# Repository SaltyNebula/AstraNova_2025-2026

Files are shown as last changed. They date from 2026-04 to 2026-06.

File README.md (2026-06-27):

# AstraNova: UKSEDS National Rocketry Championship 2025-26

**UKC AstraNova** is a student rocketry team from the **University of Kent**, competing in the **UKSEDS National Rocketry Championship (NRC) 2025-26**. This repository is the team's full project record, organised by subsystem; propulsion, structures, recovery, the customer payload, the avionics and rideshare payload, the systems engineering and design reviews, and the supporting documentation. The mission: design, build, and fly a rocket that reaches **670 m**, carries a customer payload alongside the team's own rideshare payload, records its flight data on-board, and recovers safely within **1 km** of the launch site.

> **Flight outcome:** the rocket flew a clean, stable, vertical boost, which validated the aerodynamic and stability design. At apogee it pitched over rather than nosing straight down, so the recovery flight computer's near-freefall deployment condition never triggered and the vehicle came in ballistic. The airframe was lost; the avionics board survived intact. The team took home a UKSEDS **"RUD of the Day"** plaque. The recovery and avionics failures are diagnosed honestly in the [post-mortem](#flight-outcome-and-post-mortem).

AstraNova rocket

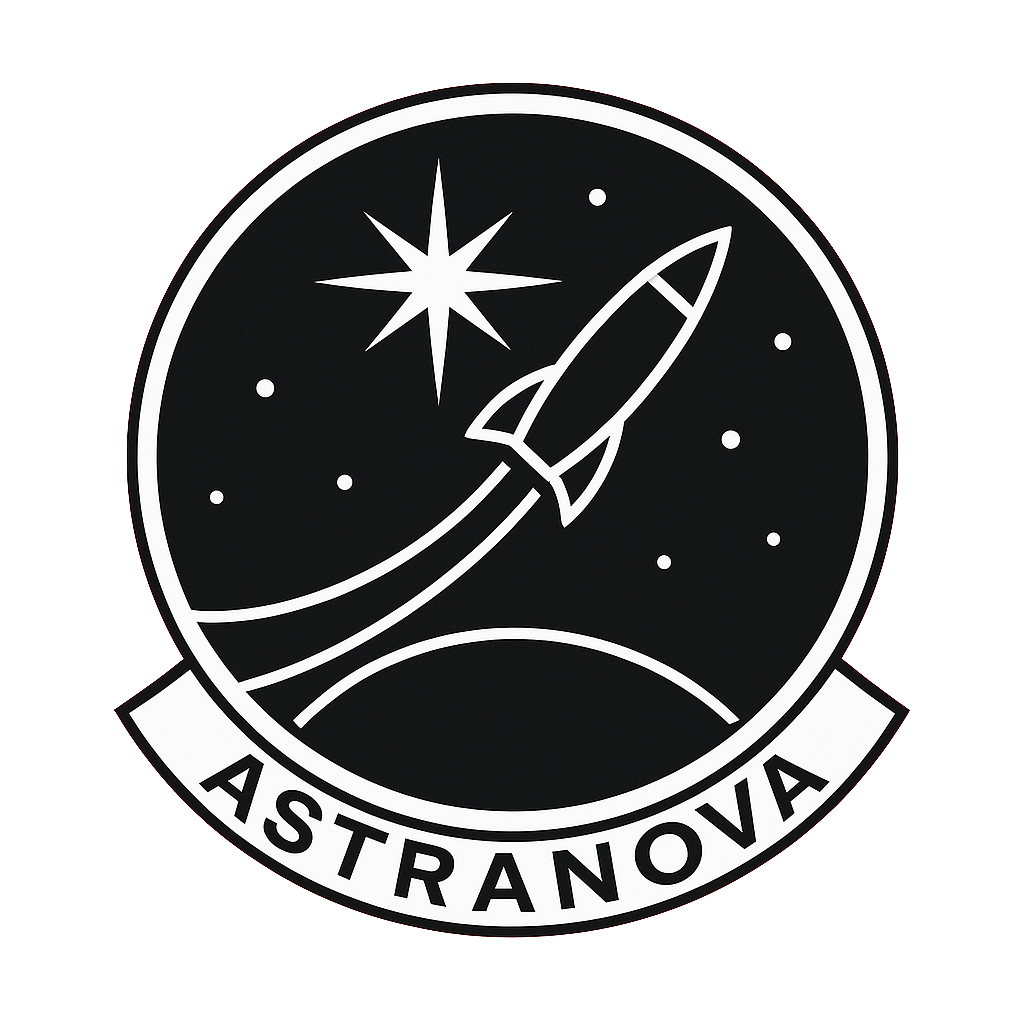
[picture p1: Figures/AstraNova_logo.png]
Team Logo


## Summary

The vehicle is a 68.9 cm, 769 g cardboard-airframe rocket flying on a **Cesaroni Pro29 108G68-13A** motor (2-grain 29 mm, 107.8 Ns total impulse, ~1.6 s near-constant burn), targeting **670 m (about 2200 ft)**. It carries two payloads: a competition **customer payload (CPD)** powered from the airframe, and the team's own **rideshare payload (the RPD)**. The RPD is a custom flight data logger that records the flight and reports peak altitude on board. Stability sits between *1.75 to 2.5 calibre** throughout ascent, and the final design clears the rail at **19.7 m/s**. Recovery is a nose-cone separation event driven by a flash-paper ejection charge and a **Mercury V1** flight computer on an isolated battery, deploying a 24" Spherachute. The project is documented end to end through the Critical Design Review, Manufacturing Review, and Flight Readiness Review, with a full requirement compliance matrix and mass, power, and financial budgets. The rocket flew, the ascent was stable and straight, and two things then went wrong; both are written up below because the lessons are the real output.

## Key points

- **Mission.** Reach 670 m, carry both payloads, retrieve flight data, and recover within 1 km of the pad, in full compliance with UKSEDS NRC safety rules.
- **Propulsion.** Cesaroni Pro29 108G68-13A; a 2-grain 29 mm motor chosen for its near-constant thrust, giving a steady burn and enough early thrust to clear the rail at speed.
- **Structures.** Cardboard body tube (about 50 mm internal diameter), four lightweight plywood trapezoidal fins, and an ABS-GF (glass-filled ABS) Ogive nose cone with a tight-fitting shoulder; total length 68.9 cm, mass 769 g, validated to hold a 2 kg suspended load without significant deflection.
- **Stability and ascent.** Stability margin held at 2.44 calibres; rail exit at 19.7 m/s; the flight confirmed a stable, vertical boost.
- **Recovery.** Mercury V1 altimeter and flight computer on an independent, isolated battery; flash-paper ejection charge fired by an igniter; nose-cone separation; 24" Spherachute with swivel; Kevlar shock cords over 2 m.
- **Customer payload (CPD).** Powered over a regulated 5 V bus through a keyed XT30 connector from a 4 A buck converter; unpressurised bay for barometric operation; mounted on a removable 3D-printed avionics sled with a bayonet-style twist lock.
- **Rideshare avionics (the RPD).** A from-scratch 2-layer PCB (102 g installed); Raspberry Pi Pico 2 (RP2350), Waveshare 10-DOF IMU (ICM-20948 + BMP280), micro-SD logging, 2.9" e-paper readout, DHT22, buzzer and status LED; barometric altitude at 50 Hz; CSV logging with a Python plotting script; on-board apogee display that holds its value without power; silkscreened team logo.
- **Power.** Shared 7.4 V 2200 mAh 2S Li-ion pack (18650CA-2S-3J, 2.2 A max discharge); a 4 A buck converter feeds the customer payload, an LDO chain feeds the RPD; about 50 minutes of runtime against a combined draw near 1.56 A.
- **Systems and documentation.** CDR, MR, and FRR submissions, a full NRC requirement compliance matrix, and mass, power, and financial budgets all live in this repository.

## Team

University of Kent; supported by the university Physics Society (PhySoc).
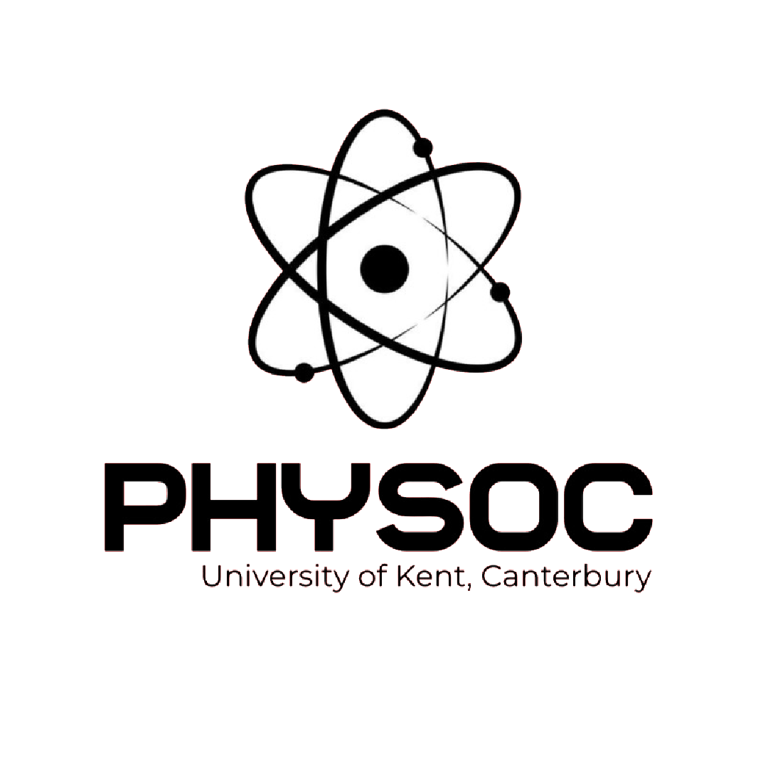
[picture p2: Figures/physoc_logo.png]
Team Logo
![PHYSOC Logo](

| Name | Role | Year / Course |
| --- | --- | --- |
| Cara-Alexandra Hefer | Team Lead / Systems Engineer | 1st / Astronomy, Space Science and Astrophysics |
| Calum Lewis | Vice Team Lead / Avionics Lead | 2nd / Electrical and Electronic Engineering |
| Lucian Willcock | Payload Lead / Avionics | 1st / Physics with Astrophysics |
| Arda Aydinlar | Systems and Structures Engineer | 2nd / Physics with Astrophysics |
| Theodoros Zilios | Recovery / CAD (Propulsion and Recovery) | 1st / Mechanical Engineering |
| Adam McGrath | Recovery Technician | 2nd / Physics |
| Alexander Barry Dee | Propulsion Engineer | 2nd / Physics with Astrophysics |
| Jack Oliver Shorey | Propulsion Engineer | 4th / Physics with Astrophysics |
| Robert Charles Langley Parry | Structural Engineer | 2nd / Ecology and Conservation |

## Subsystems

Each subsystem has its own folder; the highlights and owners are below.

**Systems** (`Systems/`; Cara, Arda). Mission definition, requirement compliance across the MOR, SMN, SAR, ESS, RRS, MIS, CPD, and RPD requirement sets, the mass, power, and financial budgets, and the CDR, MR, and FRR review submissions.

**Propulsion** (`Propulsion/`; Alexander, Jack). Motor selection and characterisation around the Cesaroni Pro29 108G68-13A, thrust-curve analysis, and the rivet-retained 3D-printed motor mount with vibration and compression testing.

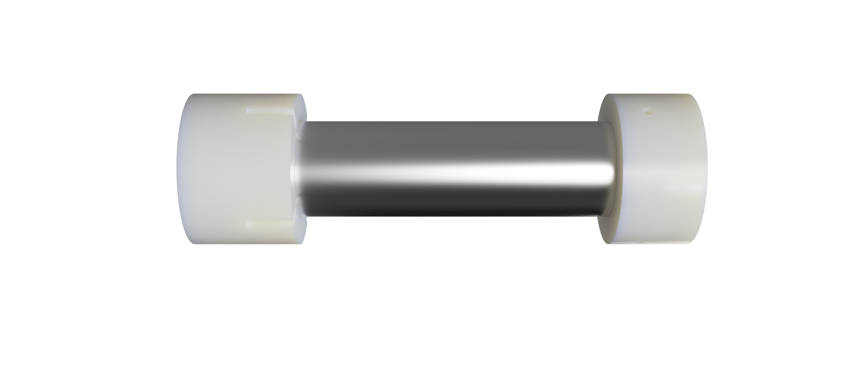
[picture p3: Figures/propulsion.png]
Propulsion: motor mount


**Structures** (`Structures/`; Robert, Arda; CAD by Theodoros). Airframe and fins; a cardboard body tube, four plywood trapezoidal fins chosen for low mass, and an Ogive nose cone, load-tested above 2 kg; OpenRocket model and flight simulation.

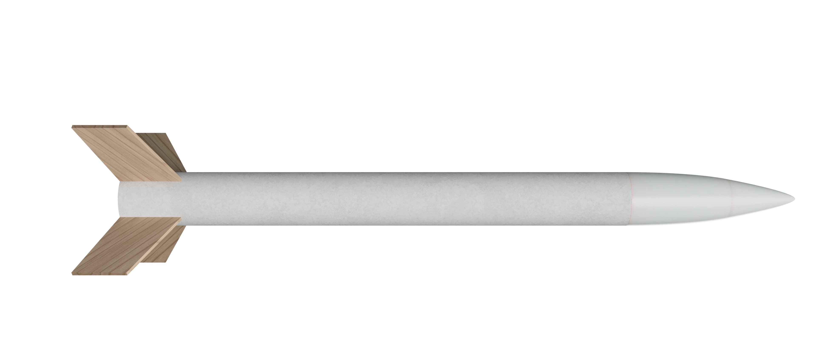
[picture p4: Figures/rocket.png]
Structures: airframe and fins


**Recovery** (`Recovery/`; Theodoros, Adam; CAD by Theodoros). Nose-cone separation system and nose cone;  ABS-GF nose cone. a flash-paper ejection charge, a Mercury V1 flight computer on an isolated battery, a 24" Spherachute, and Kevlar shock cords, all kept electrically isolated from the rest of the vehicle.

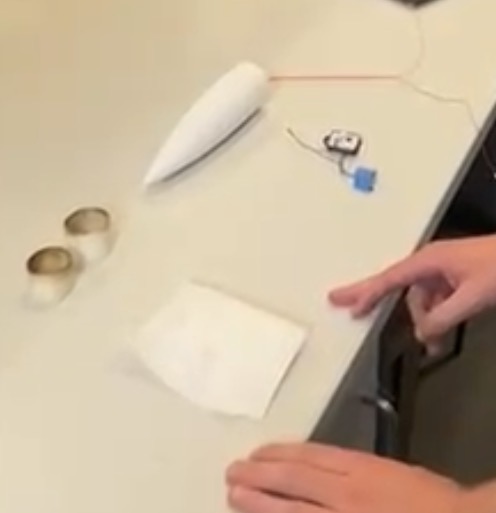
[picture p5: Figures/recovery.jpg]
Recovery system


**Payloads** (`CPD/` and `RPD/`; Lucian and Calum on Payloads).The custom flight data logger; PCB design in Fusion 360 Eagle and fabrication at JLCPCB with in-house SMD assembly (`Avionics/`), and the RP2350 firmware and recorder design (`RPD/`), covering the flight-data, apogee-display, and additional-sensor requirements.

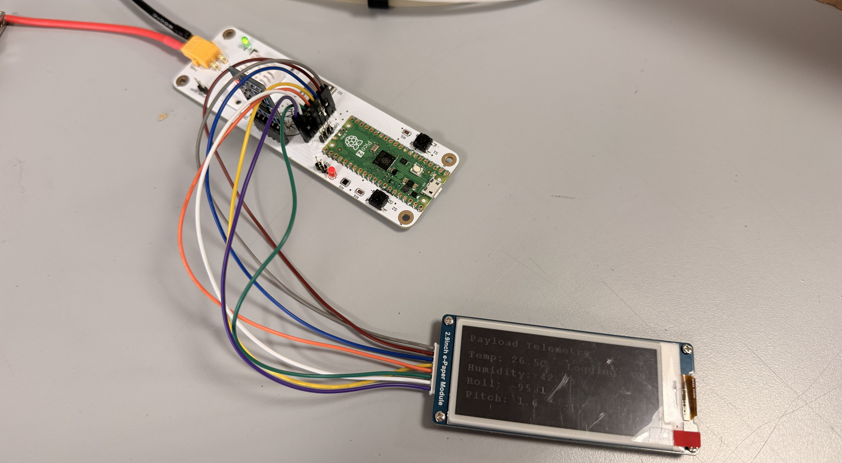
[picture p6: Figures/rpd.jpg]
Payload integration


**Avionics** (`Avionics/`; Calum and Lucian on Avionics). Overseeing all electronics, including RPD, CPD, and recovery integration and mechanical fit; powering over the regulated 5 V XT30 bus, the unpressurised bay, and the avionics sled and adapter interface. 
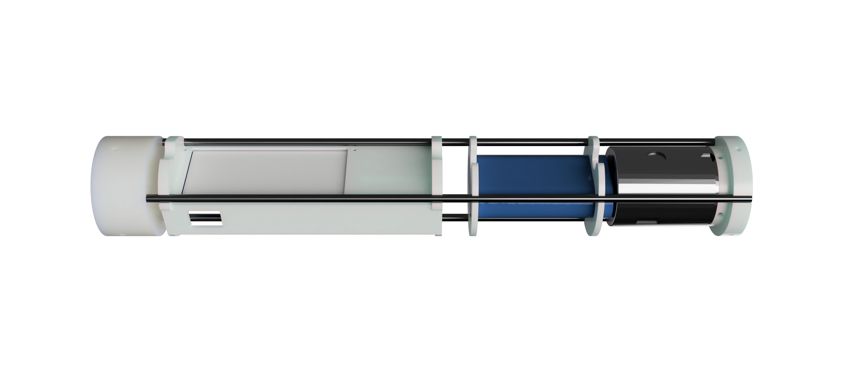
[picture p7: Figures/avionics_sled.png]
Avionics: the RPD board


## Flight outcome and post-mortem

### What went well

- **Stable, vertical ascent.** The boost was clean and straight, validating the aerodynamic and stability design; the stability margin held in the intended 1.75 to 2.5 calibre band and the vehicle tracked straight off the rail.
- **ABS-GF thermal margin.** The printed parts were made in ABS-GF for its rigidity and heat resistance, since the team was concerned the motor casing might melt nearby plastic. In flight the heat was not an issue at all; the parts came through untouched.
- **Flew on a substitute motor.** The vehicle flew successfully even though it launched on a motor it had not been tuned for (see below), which speaks to margin in the design.

### What went wrong

**Motor substitution.** The motor the team had ordered through UKSEDS was taken before launch, so AstraNova was issued a different motor that the flight had not been calculated or simulated for. The rocket flew regardless, but this changed the expected flight profile.

**Recovery (vehicle level).** Deployment depended on the Mercury V1 detecting a near-freefall, under 1 g condition at apogee. Because the rocket flew so straight on the way up, it carried that momentum over the top and pitched sideways rather than nosing into a clean vertical descent; it never "went straight down." Broadside, aerodynamic load kept the measured acceleration above 1 g, so the deployment window never opened and the rocket came in ballistic. The nose and carbon rods were destroyed on impact. The lesson is direct: a single accelerometer threshold is an unreliable apogee and deploy trigger, because a stable, non-vertical attitude at apogee never produces the expected freefall reading.

**RPD (avionics).** The board powered up, beeped, and wrote its startup calibration row, but logged no flight data. The cause was a **shared-source power brownout**. The 18650CA-2S-3J pack is rated to 2.2 A maximum discharge, and the steady draw (about 1.5 A for the customer payload plus the rideshare) already sat near 1.56 A, leaving very little headroom; the high-dropout regulator chain then gave away most of the voltage margin, and with no bulk capacitance for transient ride-through, the e-paper refresh bursts and the arm-time SD write transient pushed the pack past its limit and dropped the rail below the RP2350 brownout threshold. The board reset mid-arm and only the startup row reached the card.

→ **Full write-up: [Documentation/Avionics_RPD_and_Flight_Postmortem.md](Documentation/Avionics_RPD_and_Flight_Postmortem.md)**

## Quick specs

| Parameter | Value |
| --- | --- |
| Competition | UKSEDS National Rocketry Championship 2025-26 |
| University | University of Kent |
| Target apogee | 670 m (about 2200 ft) |
| Motor | Cesaroni Pro29 108G68-13A (2-grain 29 mm, 107.8 Ns) |
| Airframe | cardboard body tube, four plywood fins, ABS-GF Ogive nose |
| Length / mass | 68.9 cm / 769 g |
| Stability | 2.44 calibres |
| Rail exit speed | 19.7 m/s |
| Recovery | Mercury V1, flash-paper charge, 24" Spherachute |
| Battery | 7.4 V 2200 mAh 2S Li-ion (18650CA-2S-3J, 2.2 A max discharge) |
| Avionics MCU | Raspberry Pi Pico 2 (RP2350) |
| Avionics sensors | ICM-20948, BMP280, DHT22 |
| Avionics readout | 2.9" e-paper, on-board peak altitude |
| RPD mass | 102 g |

## Repository structure

```
Avionics/        avionics battery, power design and sled
RPD/             rideshare flight data logger hardware and electronics (PCB design)
CPD/             customer payload integration and interface
Propulsion/      motor selection and mount
Recovery/        recovery system design, nose cone,
Structures/      airframe, fins, OpenRocket model
Systems/         systems engineering, requirement traceability
Documentation/   design notes and the avionics + flight write-up, design reviews (CDR, MR, FRR)
Figures/         photos and renders used in the README
LICENSE
README.md
```

## License

Released under the MIT License; see [`LICENSE`](LICENSE). If you would rather the documents and figures carry a content licence (for example CC BY 4.0) separately from the code, the repository can be dual-licensed.

## Documentation note

The engineering and conclusions here are the team's own. An AI assistant was used as a writing aid to structure and draft this README and the flight write-up from the team's design reviews and post-flight diagnosis.

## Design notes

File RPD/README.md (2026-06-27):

# RPD Hardware

The custom 2-layer PCB for the **RPD**, AstraNova's rideshare flight data logger. Designed in **Fusion 360 (Eagle)** and fabricated at **JLCPCB**, with SMD assembly done in-house with engineering lab-tech support. Installed mass is about **102 g** including the sled.

> The flight-day power failure and the board-level fixes are in [`../Documentation/Avionics_RPD_and_Flight_Postmortem.md`](../Documentation/Avionics_RPD_and_Flight_Postmortem.md); see [Known issues](#known-issues-and-planned-fixes).

## Components

| Subsystem | Part | Interface |
| --- | --- | --- |
| MCU | Raspberry Pi Pico 2 (RP2350), SMD-mounted | ; |
| IMU + barometer | Waveshare 10-DOF (ICM-20948 + BMP280) | I2C1 |
| Storage | micro-SD card | SPI0 |
| Display | 2.9" e-paper V2 (296 x 128) | SPI1 |
| Environment | DHT22 | 1-wire |
| Level shifter | CD74HC4050 (Rev V2 only) | ; |
| Indicators | buzzer, green/red status LEDs, ARM / ZERO buttons | GPIO |
| Customer payload supply | 4 A buck converter, 5 V, female XT30 | ; |
| Rideshare supply | LD1117 LDO chain | ; |
| Power in | 2S Li-ion (18650CA-2S-3J, 7.4 V 2200 mAh) | ; |

The PCB carries a **silkscreened team logo** (requirement RPD-005).

## Power architecture

```
2S Li-ion --+-- buck converter (5V, 4A) ----------------- customer payload (XT30)
            |
            +-- LD1117S50 (5V) -- LD1117S33 (3.3V) ------ RPD rail
```

The customer payload and the RPD share only the **battery input terminal**; downstream each has its own regulation. This shared source, combined with the regulator cascade and a lack of bulk decoupling, is what produced the flight-day brownout.

## Board revisions

- **Rev V2(figure 1), flight board.** ENIG finish on black soldermask; includes the CD74HC4050 level-shifter path. This is the board that flew, and it survived the ballistic impact intact.
- **Rev B(alt), test article.** HASL finish; level shifter removed (redundant for all-3.3 V logic) and the SD card wired directly. Built to validate the simplification before committing it to a flight spin.

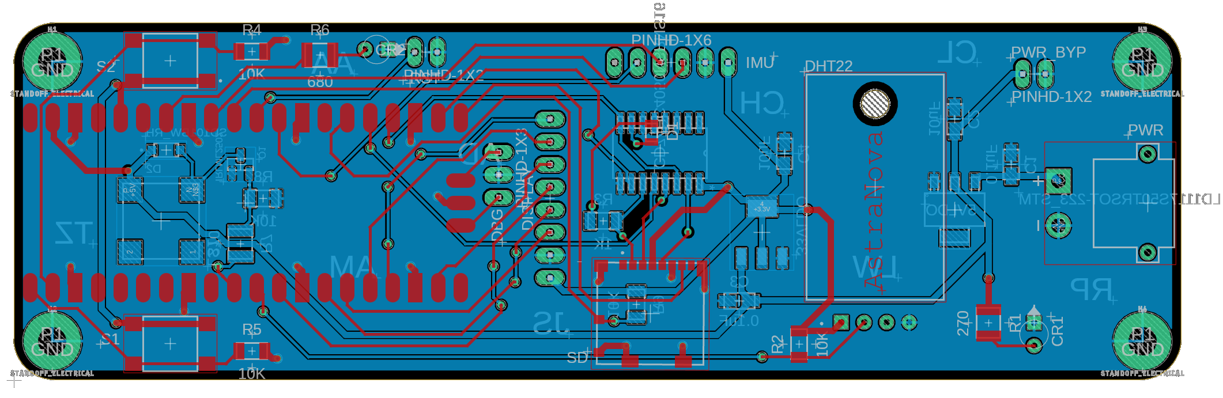
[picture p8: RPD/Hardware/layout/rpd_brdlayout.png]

*Figure 1: PCB Layout*

## Fabrication notes

- 2-layer board, bottom-layer ground plane, hand-routed critical nets (paired I2C, SPI to SD and e-paper, 0.5 to 1 mm power traces).
- JLCPCB standard 2-layer process; confirm design rules before ordering (min trace and clearance 0.127 mm, min via 0.3 mm hole / 0.6 mm annular ring).
- Power section soldered and voltage-checked first, before populating the rest.
  
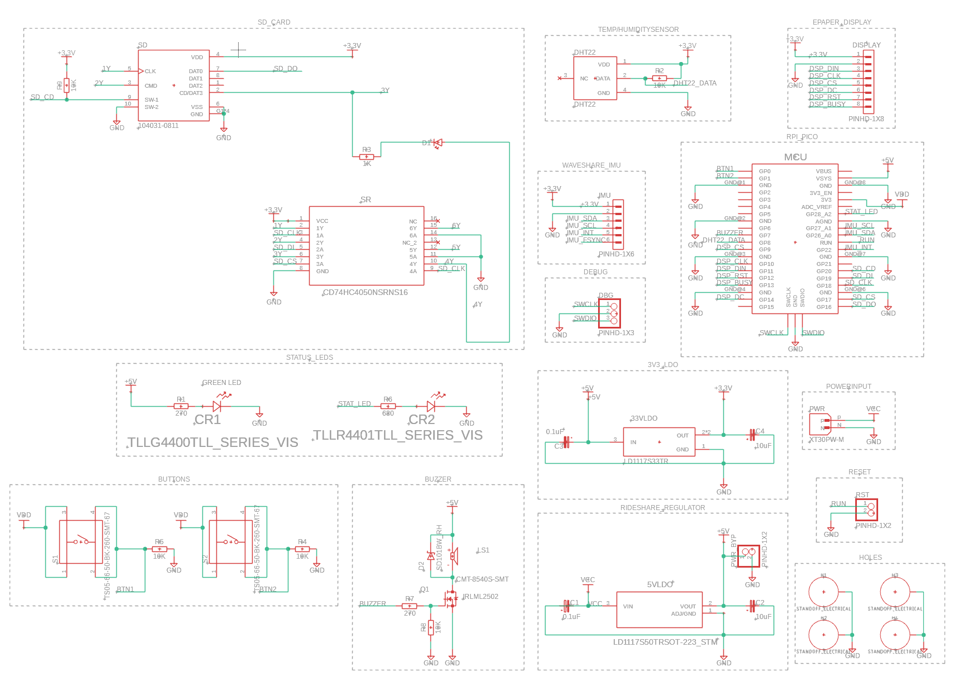
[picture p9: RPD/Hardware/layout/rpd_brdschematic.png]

*Figure 2: Schematic of PCB(also see schematic in `../RPD/Hardware/schematic.pdf ` )*

## What lives in this folder

```
hardware/
  schematic.pdf          exported schematic
  layout/                board renders and screenshots
  gerbers/               fabrication outputs (Rev V2 ENIG, Rev B HASL)
  bom.csv                bill of materials
  source/                Fusion 360 / Eagle design files (.sch, .brd)
```

Board photos used by the top-level README go in `../figures/` (for example `avionics.jpg`).

## Known issues and planned fixes

The RPD recorded no flight data due to a shared-source brownout. The hardware changes, in order of effect:

1. **Independent battery for the RPD**, decoupled from the customer rail; this alone breaks the failure chain.
2. **Drop the 5 V to 3.3 V cascade** for a single regulator off the pack, to recover the sag margin the high-dropout LD1117 chain gave away.
3. **Add bulk capacitance** at the board input and next to the SD card and e-paper, for transient ride-through.

See the [full write-up](../Documentation/Avionics_RPD_and_Flight_Postmortem.md) for the reasoning.

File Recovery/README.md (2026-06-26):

# Recovery System

How AstraNova brings the rocket back: a nose-cone separation event at apogee, commanded by a flight computer and deploying a parachute, with the recovery electronics kept fully isolated from the rest of the vehicle.

## Flight computer

Recovery is commanded by a **Mercury V1 altimeter and flight computer** ([product support](https://www.altimetercloud.com/support/mercuryv1/)), running on its own battery and electrically isolated from the payload electronics. It uses barometric pressure and onboard acceleration to determine flight phase and fire the ejection charge. It is UKRA qualified, externally disarmable before launch, and uses no tilt switches.

## Choosing the deployment method

We could not rely on black powder; access was uncertain under strict regulations and we were not able to source any. That left two charge options, both with prior competition heritage:

- a **nichrome burn wire** to melt through a plastic retention, and
- **flash paper** as a fast pressure charge.

Both have flown in competition, so each had a basis. Flash paper behaves most like black powder (a quick pressure pulse rather than a slow burn-through), so we selected flash paper, fired by an igniter.

A **mechanical deployment mechanism** (a servo or motor-driven release) was also considered and rejected; structures judged it too heavy for the mass budget.

## Flight computer versus the motor's timed ejection charge

Many teams deploy using the motor's built-in timed ejection charge, where a delay is set on the ground before flight. We chose a flight computer instead, deploying on **detected apogee** rather than a preset time, for a more controllable ascent and a deployment tied to the actual flight rather than an assumed one. That decision matters in the [trade-off](#flight-outcome-and-trade-off) below.

## Parachute and shock cords

A **24" Spherachute** with swivel slows the descent to within the recovery requirement; OpenRocket showed a descent rate around 9.5 m/s, comfortably under the 15 m/s limit. **Kevlar shock cords** over 2 m connect the nose cone and main airframe, sized to take the deployment load and prevent full separation, with eye bolts secured by nuts.

Parachute deployment test
*Figure 1: Flashpaper test for recovery section(parachute was tied together).*

## Flight outcome and trade-off

On the day, the parachute did not deploy. The rocket flew very straight on the way up, which speaks well of the aerodynamic design; it then carried that momentum over the top and pitched sideways at apogee rather than nosing straight down. The flight computer's near-freefall (under 1 g) deployment condition therefore never triggered, and the vehicle came in ballistic.

The honest trade-off worth recording:

- **The flight-computer choice was vindicated in one respect.** We were issued a different motor than planned on the day. A preset timed ejection charge, tuned to the original motor's expected apogee time, would almost certainly have fired at the wrong moment. Apogee-based deployment is immune to that, because it responds to the actual flight.
- **It also added complexity that most teams did not take on,** and that complexity is where the failure lived. Deployment was gated on a single accelerometer threshold, which a stable, non-vertical attitude at apogee never satisfies.

So the lesson is not "do not use a flight computer"; the flight computer was the more adaptable choice and protected us from exactly the motor swap that would have defeated a timed charge. The lesson is in the **deployment condition**: a barometric apogee detection (a positive-to-negative crossing of vertical velocity), or a multi-signal gate, would have fired regardless of attitude. Configure the trigger to the physics of apogee, not to a freefall assumption.

For the parallel power-side failure on the rideshare recorder, see the [avionics post-mortem](../Documentation/Avionics_RPD_and_Flight_Postmortem.md).

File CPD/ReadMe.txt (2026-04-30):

 The following files have been provided:

- LVA_no_XT30_V1
	- Formats: .stl, .stp, .ipt
	- Use: this is the launch vehicle adapter (LVA) that YOU are expected to manufacture and include in your designs. It is expected that this will be done with a 3d printer, please contact us at rocketry@ukseds.org if you do not have access to one of these. This version of the LVA has no cutout for the XT30 connector. As a reminder, as per requirement NRC MRD-CPD-004, you will be providing power to "the customer's" payload. You have two options to power this payload, either from the bottom or the top through the LVA. This LVA file is provided for if you want to provide power from the bottom. This allows you to place ejection charges behind the LVA and since there is not cutout for the XT30 connector, this should mitigate the hot gases from damaging the payload.
	- Can I modify this file? Yes - you may modify this file to help integrate it into your design. However, please remember that the mating interface is fixed as this needs to match "the customer's" payload. Therefore, we would recommend only modifying the parts' diameter and if you do so, you will need to provide some longer bolts to mount the payload. If you intend to modify this part, we recommend that you drop us a message at rocketry@ukseds.org with a .stl of your modified version and a description of what you have changed and we can check it quickly for any issues.

- LVA_XT30_V1
	- Formats: .stl, .stp, .ipt
	- Use: this is the other version of the launch vehicle adapter (LVA) that YOU are expected to manufacture and include in your designs. It is expected that this will be done with a 3d printer, please contact us at rocketry@ukseds.org if you do not have access to one of these. This version of the LVA has a cutout for the XT30 connector. As a reminder, as per requirement NRC MRD-CPD-004, you will be providing power to "the customer's" payload. You have two options to power this payload, either from the bottom or the top through the LVA. This LVA file is provided for if you want to provide power to the top of the payload, through the LVA.
	- Can I modify this file? Yes - you may modify this file to help integrate it into your design. However, please remember that the mating interface is fixed as this needs to match "the customer's" payload. Therefore, we would recommend only modifying the parts' diameter and if you do so, you will need to provide some longer bolts to mount the payload. If you intend to modify this part, we recommend that you drop us a message at rocketry@ukseds.org with a .stl of your modified version and a description of what you have changed and we can check it quickly for any issues. You may also modify the size of the XT30 cutout. We highly recommend carrying out a fit check to see if your XT30 connector passes through this as early as possible.

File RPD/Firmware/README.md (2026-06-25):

# RPD Firmware

Flight firmware for the **RPD (Rocket Position Data recorder)**, AstraNova's rideshare flight data logger. It runs on a **Raspberry Pi Pico 2 (RP2350)** under the Arduino framework, logging a 10-DOF IMU, a barometer, and a DHT22 to micro-SD through the flight, and reporting peak altitude on a 2.9" e-paper screen after landing.

> The flight-day failure and the planned changes are documented in [`../Documentation/Avionics_RPD_and_Flight_Postmortem.md`](../Documentation/Avionics_RPD_and_Flight_Postmortem.md); see [Known issues](#known-issues-and-planned-fixes) below.

## Files

| File | Purpose |
| --- | --- |
| `FlightLogger.ino` | Main firmware; flight state machine and SD logging |
| `Waveshare_10Dof-D.*` | IMU and barometer driver (ICM-20948 + BMP280) |
| `epd2in9_V2.*` | 2.9" e-paper V2 driver |
| `epdpaint.*` | Framebuffer and drawing primitives |
| `epdif.*` | e-paper SPI interface and pin definitions |
| `fonts.h`, `font8/12/16/20/24.cpp` | Bitmap fonts for the display |

External dependency: an Arduino DHT sensor library (for the DHT22).

## Pin map

| Function | Pin | Bus |
| --- | --- | --- |
| ARM button | GP0 | GPIO |
| ZERO button | GP1 | GPIO |
| Status LED | GP28 | GPIO |
| Buzzer | GP7 | GPIO |
| SD card detect | GP20 | GPIO |
| DHT22 | GP8 | 1-wire |
| IMU SDA / SCL | GP26 / GP27 | I2C1 |
| SD MISO / CS / SCK / MOSI | GP16 / GP17 / GP18 / GP19 | SPI0 |
| e-paper CS / SCK / MOSI | GP9 / GP10 / GP11 | SPI1 |
| e-paper RST / BUSY / DC / PWR | GP12 / GP13 / GP14 / GP15 | SPI1 |

## Build and flash

1. Install the [arduino-pico](https://github.com/earlephilhower/arduino-pico) core and select **Raspberry Pi Pico 2** as the board.
2. Install an Arduino DHT22 library through the Library Manager.
3. Keep the driver files in this folder alongside `FlightLogger.ino` (or copy them into your Arduino libraries directory).
4. Compile and flash over USB; hold **BOOTSEL** while connecting for the first flash.
5. Insert a FAT-formatted micro-SD card.

## Flight state machine

`IDLE` to `ARMED` to `ASCENT` to `DESCENT` to `LANDED`, all autonomous once armed.

| Transition | Condition |
| --- | --- |
| IDLE to ARMED | ARM button; sets the ground baseline and opens the log |
| ARMED to ASCENT | acceleration > 3 g, debounced 150 ms |
| ASCENT to DESCENT | barometric altitude falling for 500 ms (apogee) |
| DESCENT to LANDED | AGL < 330 ft, altitude stable within a 10 ft band, ~1 g, held 5 s |
| any flight state to LANDED | 180 s time failsafe |
| LANDED to IDLE | ARM button (reset) |

The accelerometer is configured to **+/-16 g** full-scale, since boost peaks would clip lower settings.

## Buttons

- **ARM** (GP0): in `IDLE`, arms the recorder and begins logging; in `LANDED`, resets to `IDLE`.
- **ZERO** (GP1): rebaselines the displayed relative altitude; does not touch the log.

## Log format

Written to `flightlog.csv`, flushed every second. A `STARTUP` calibration row is written at power-on, `LOG` rows once armed:

```
TimeMs,AccelX,AccelY,AccelZ,GyroX,GyroY,GyroZ,DHTTempC,DHTHum,IMUTempC,AltitudeM,Event
```

A Python script (see the requirement record for RPD-003) turns the CSV into an altitude-versus-time plot in feet.

## Known issues and planned fixes

From the post-mortem, the recorder logged no flight data on the day due to a shared-source power brownout. The firmware-side changes that follow from it:

- Set the armed flag and **start logging before any display call**, so a display problem can never gate logging.
- Put a **timeout on every e-paper busy-wait**; the stock driver waits on the BUSY pin with no timeout, which can hang the loop if the panel is unresponsive.
- Optionally run the display on the RP2350's **second core**, so it physically cannot stall the state machine or SD logging.

These pair with the hardware fix (an independent supply for the RPD); see the [full write-up](/Documentation/Avionics_RPD_and_Flight_Postmortem.md).

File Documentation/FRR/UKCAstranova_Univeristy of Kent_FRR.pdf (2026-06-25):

# NATIONAL ROCKETRY CHAMPIONSHIP

# Flight Readiness Review

## UKC Astranova

Cara-Alexandra Hefer, Calum Lewis, Arda Aydinlar, Adam McGrath, Alex Dee, Theo Zilios, Lucian Willcock, Jack Shorey, Robert Parry

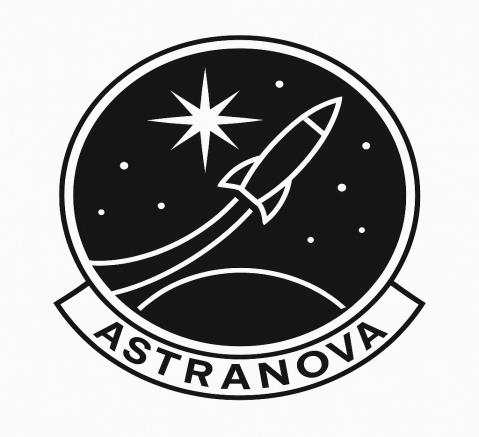
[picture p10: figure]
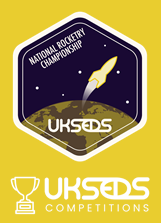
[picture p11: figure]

# Overview

Task | Status | Comments
Requirement Compliance | Complete | There is one partial due to a late delivery
Launch Vehicle Manufacture | Complete
OpenRocket Simulation | Complete
Recovery System Assembly | Complete
Recovery System Demonstration | Complete
Structural Tests | Complete

# Overview

Task | Status | Comments
Launch Vehicle Decoration | Complete
Rideshare Payload Manufacture | Complete
Rideshare Payload Code | Complete
Rideshare Payload Tests | Complete
The Customer’s Payload | Complete
Competition Day Procedure | Complete

# Requirement Compliance

Requirement ID | Met? [Yes, No, Partially] | Rational
NRC MRD-MIS-001 | Rev: A | Yes | The motor chosen and design of the rocket theoretically should reach this apogee
NRC MRD-MIS-002 | Rev: A | Yes | Dual-deployment is not being used
NRC MRD-MIS-003 | Rev: A | Yes | Rocket will be unable to reach this height
NRC MRD-MIS-004 | Rev: A | Yes | Motor was picked from provided list that complied with these guidelines
NRC MRD-MIS-005 | Rev: A | Yes | To be supplied by UKSED on the day
NRC MRD-MIS-006 | Rev: A | Yes | Confirmation email has been received
NRC MRD-MIS-007 | Rev: A | Yes | The RPD weighs 102g
NRC MRD-MIS-008 | Rev: A | Yes | The rocket won’t reach further than 750m

# Requirement Compliance

Requirement ID | Met? [Yes, No, Partially] | Rational
NRC MRD-CPD-001 | Rev: B | Yes | A 5V 4A buck converter with an XT30 connector shall be used to power the CPD
NRC MRD-CPD-002 | Rev: A | Yes | See NRC TSN-ESS-001 | Rev: A
NRC MRD-CPD-003 | Rev: A | Yes | 18650CA-2S-3J battery has a max discharge current of 2.2A CPD has current draw of 7.5W/5V = 1.5A
NRC MRD-CPD-004 | Rev: B | Yes | The buck converter used for powering the CPD as an XT30 connector
NRC MRD-CPD-005 | Rev: A | Yes | AstraNova will provide an sd card for the CPD
NRC MRD-CPD-006 | Rev: B | Yes | The avionics sled has a a launch vehicale adapter mounted at the top for the CPD
| NRC MRD-CPD-007 | Rev: B | Yes | As per the model the the avionics sled has an diameter of 50mm and clearance of over 53mm

# Requirement Compliance

Requirement ID | Met? [Yes, No, Partially] | Rational
NRC MRD-CPD-008 | Rev: B | Yes | As per the 3d assembly, the customer payload It is mounted concentricaly
NRC MRD-CPD-009 | Rev: B | Yes | Holes have been drilled into the side of the rocket for external access
NRC MRD-CPD-010 | Rev: A | Yes | The entire avionic Sled is unpressurized
NRC MRD-CPD-011 | Rev: A | Yes | AstraNova has m3 bolts to for mounting the CPD
NRC MRD-RPD-001 | Rev: A | Yes | Custom PCB designed in Fusion360, manufactured and populated in-house
NRC MRD-RPD-002 | Rev: A | Yes | BMP280 barometer, bench tested, altitude reading verified by walking up and down flight of stairs
NRC MRD-RPD-003 | Rev: A | Yes | Python script generates plot from SD card data.
| | Demonstrated in bench test video.

# Requirement Compliance

Requirement ID | Met? [Yes, No, Partially] | Rational
NRC MRD-RPD-004 | Rev: A | Yes | Code calculates and logs apogee value to SD card and OLED display.
NRC MRD-RPD-005 | Rev: A | Yes | Silkscreen is on rideshare PCB(example photo in following slides)
NRC MRD-RPD-006 | Rev: A | Yes | 10-DOF IMU logs acceleration, gyro, mag data throughout flight.
NRC TSN-MOR-001 | Rev: A | Yes | Mount has been designed to maximise strength and minimise weight. Material selected has a sufficient heat tolerance. Will fit tightly to the top , secured with screws to the body – transferring thrust from the motor to the rocket. Rear clamps also fit tightly and secured with screws to the body.
NRC TSN-MOR-002 | Rev: A | Yes | Has been tested and can withstand the force
NRC TSN-MOR-003 | Rev: A | Yes | Has been tested and can withstand the force
NRC TSN-SMN-001 | Rev: A | YES | See openrocket design

# Requirement Compliance

Requirement ID | Met? [Yes, No, Partially] | Rational
NRC TSN-SMN-003 | Rev: A | YES | See openrocket design
NRC TSN-SAR-001 | Rev: A | YES | Fins have been fixed in line with the longitudinal axis of the rocket
NRC TSN-SAR-002 | Rev: A | YES | Fin designs where tested to specification and found to be able to withstand high levels of strain
NRC TSN-SAR-003 | Rev: A | YES | See above
NRC TSN-SAR-004 | Rev: A | YES | Main body was tested with various weights in excess of 2 kg and found to be resilient to high lateral and longitudinal forces
NRC TSN-SAR-005 | Rev: A | YES | Nose cone's coupling with the main body is equal to 1 diameter of the main body.
NRC TSN-SAR-006 | Rev: A | YES | All structural parts have been tested to specification and can withstand all expected loads

# Requirement Compliance

Requirement ID | Met? [Yes, No, Partially] | Rational
NRC TSN-SAR-007 | Rev: A | Partially | Rail buttons have been ordered however have not yet arrived
NRC TSN-SAR-008 | Rev: A | YES | FEA analysis was not used for parts testing
NRC TSN-ESS-001 | Rev: A | Yes | Main battery 2S 2200mAh at ~60mA (rideshare) + customer payload at 1.5A. Total ~1.56A draw. 2200mAh at 7.8W = 50 minutes runtime.
NRC TSN-ESS-002 | Rev: A | Yes | Avionics sled can be removed by unscrewing six screws. Allows removal and arming in under 5 minutes
NRC TSN-ESS-003 | Rev: A | Yes | No single core wires have been used
NRC TSN-ESS-004 | Rev: A | Yes | The team comforms to ofcom's IR 2030 RF
| | ragulation as no radio has been used
NRC TSN-RRS-001 | Rev: A | Yes | The vehicle will have a recovery system

# Requirement Compliance

Requirement ID | Met? [Yes, No, Partially] | Rational
NRC TSN-RRS-002 | Rev: A | Yes | The speed of the vehicle will be less than 15m/s
NRC TSN-RRS-003 | Rev: A | Yes | The vehicle will not drift more than one kilometre
NRC TSN-RRS-004 | Rev: A | Yes | The flight computer used is UKRA qualified
NRC TSN-RRS-005 | Rev: A | Yes | Flight controller uses separate battery and therefore is entirely isolated from Payload's Battery
NRC TSN-RRS-006 | Rev: A | Yes | Tilt switches have not been used
NRC TSN-RRS-007 | Rev: A | Yes | The flight computer has an externally disarming mechanism
NRC TSN-RRS-008 | Rev: A | Yes | Eye bolts with screws have been used

# Requirement Compliance

Requirement ID | Met? [Yes, No, Partially] | Rational
NRC TSN-RRS-007 | Rev: A | Yes | The shock cords are above the minimum length
NRC TSN-RRS-008 | Rev: A | Yes | The shock cords are made of kevlar
NRC TSN-ARY-001 | Rev: A | Yes | Recovery conforms to CAA UAS law
NRC TSN-ARY-002 | Rev: A | Yes | Recovery conforms to UKRA safety code
NRC TSN-ARY-003 | Rev: A | Yes | We are not using active stabilisation

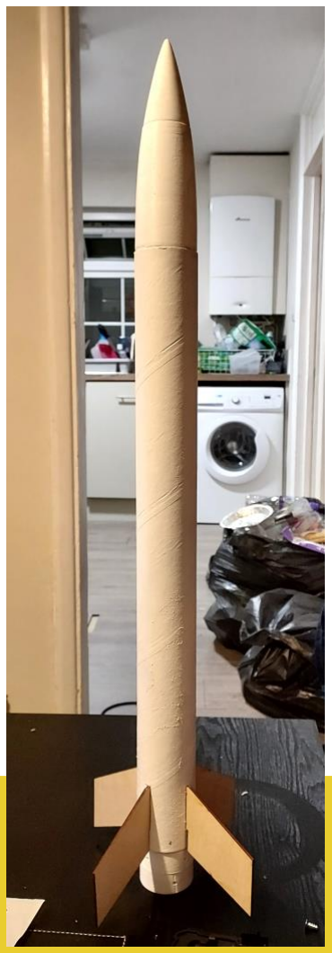
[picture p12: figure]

# Launch Vehicle Manufacture

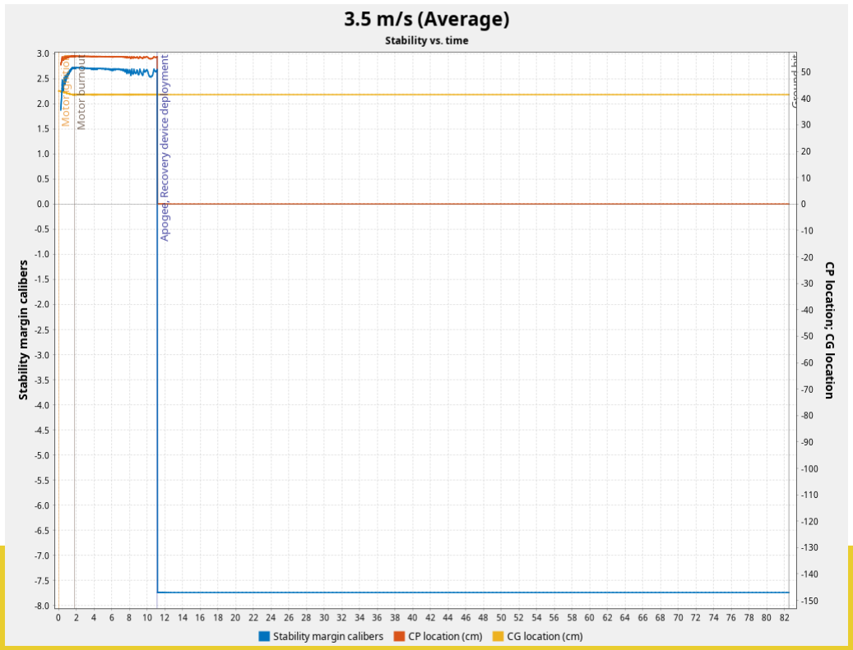
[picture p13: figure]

## OpenRocket Simulation

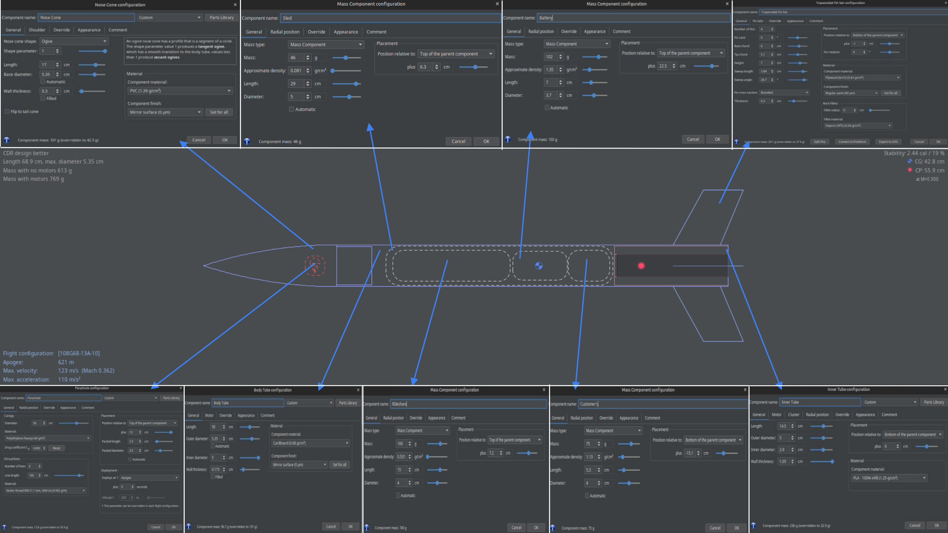
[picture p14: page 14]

# Evidence of Component Mass

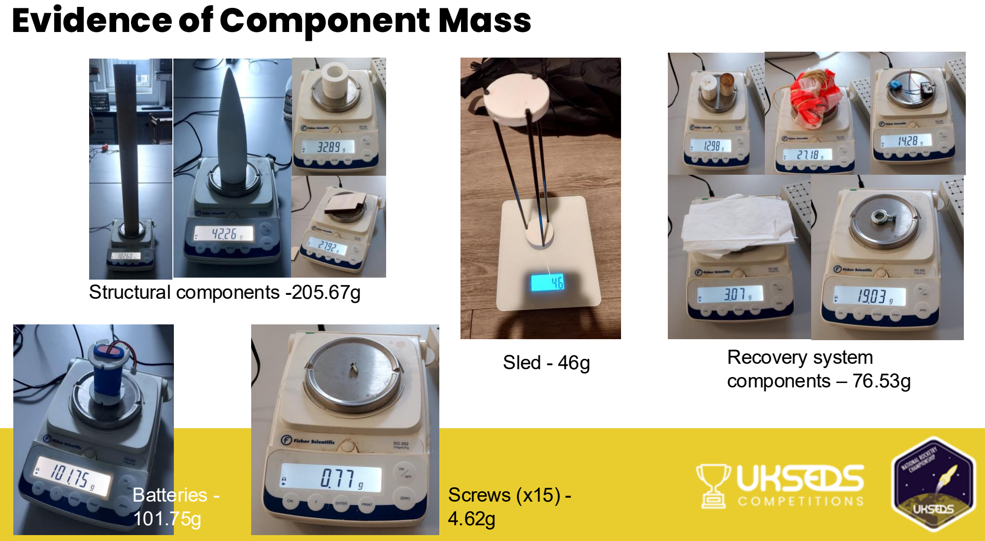
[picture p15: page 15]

Recovery system
components – 76.53g

Batteries -
101.75g

Sled - 46g

Structural components -205.67g

Screws (x15) -
4.62g

## Recovery System Assembly

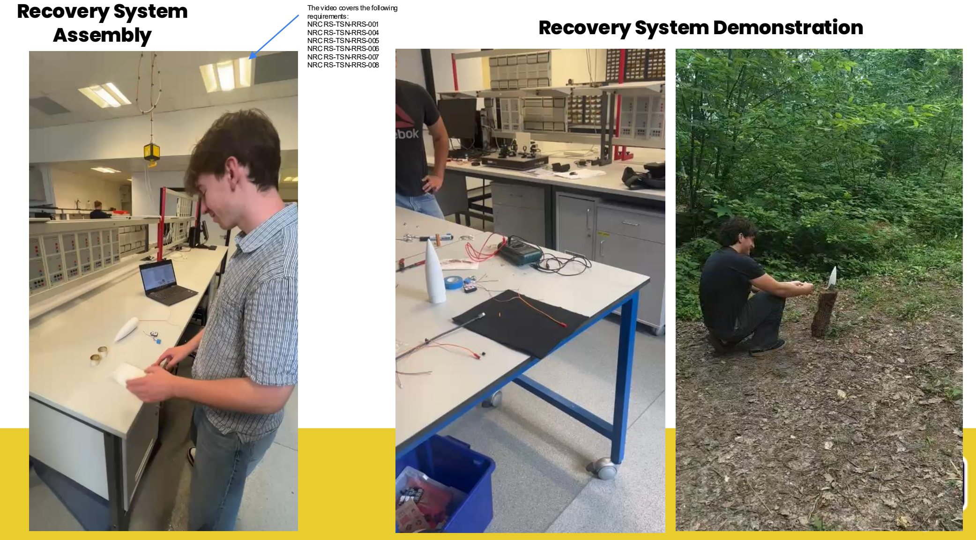
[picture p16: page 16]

The video covers the following requirements:
NRC RS

-TSN

-RRS

-001
NRC RS

-TSN

-RRS

-004
NRC RS

-TSN

-RRS

-005
NRC RS

-TSN

-RRS

-006
NRC RS

-TSN

-RRS

-007
NRC RS

-TSN

-RRS

-008

## Recovery System Demonstration

# Structural Tests

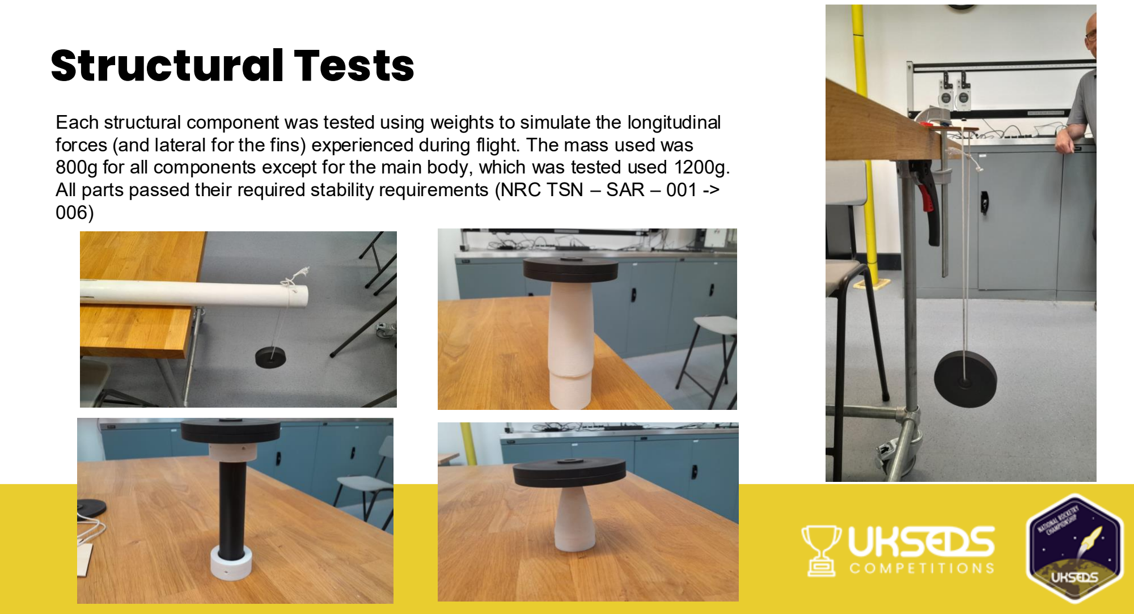
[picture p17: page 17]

Each structural component was tested using weights to simulate the longitudinal forces (and lateral for the fins) experienced during flight. The mass used was 800g for all components except for the main body, which was tested used 1200g. All parts passed their required stability requirements (NRC TSN – SAR – 001 -> 006)

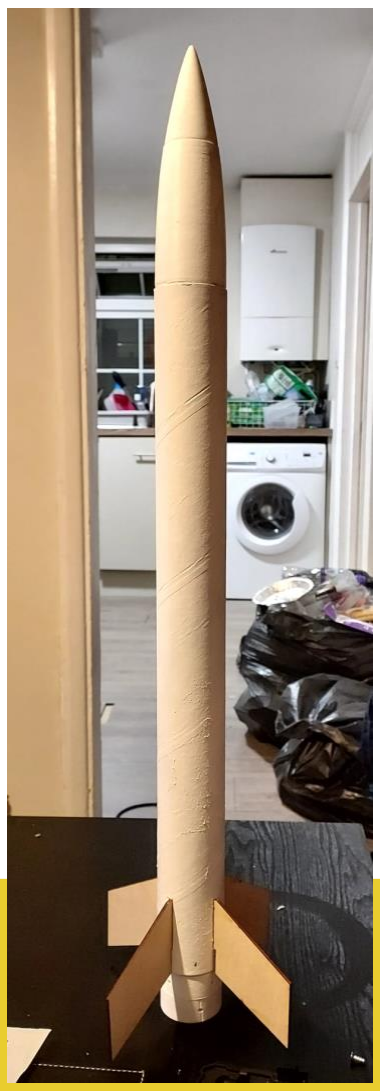
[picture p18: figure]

# Launch Vehicle Decoration

# Rideshare Payload Manufacture

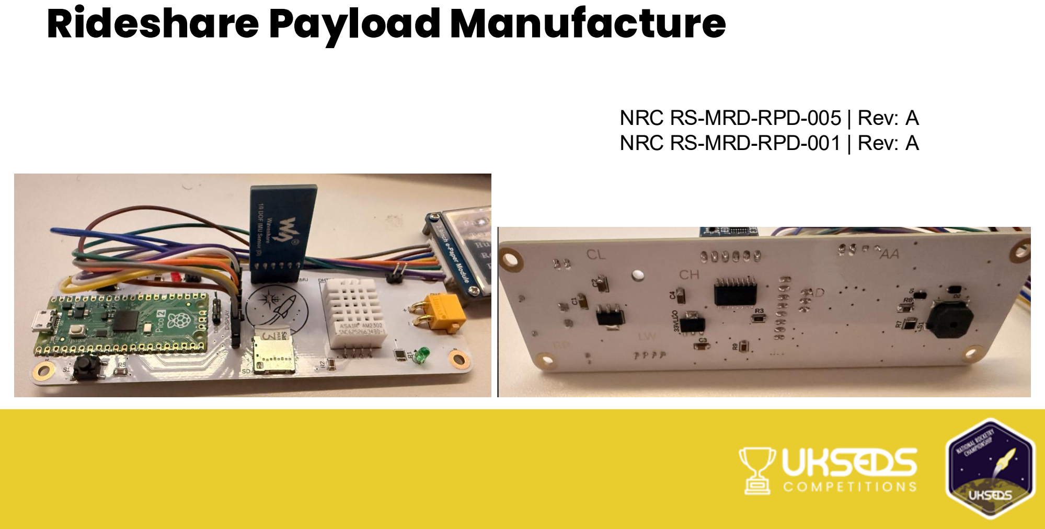
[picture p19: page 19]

NRC RS-MRD-RPD-005 | Rev: A
NRC RS-MRD-RPD-001 | Rev: A

# Rideshare Payload Manufacture

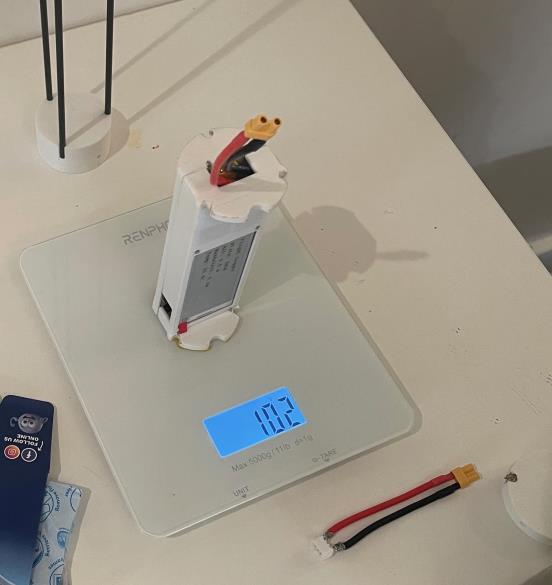
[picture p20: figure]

### NRC MRD-MIS-007 | Rev: A

Rideshare Payload Code | NRC RS-MRD-RPD-003 | Rev: A

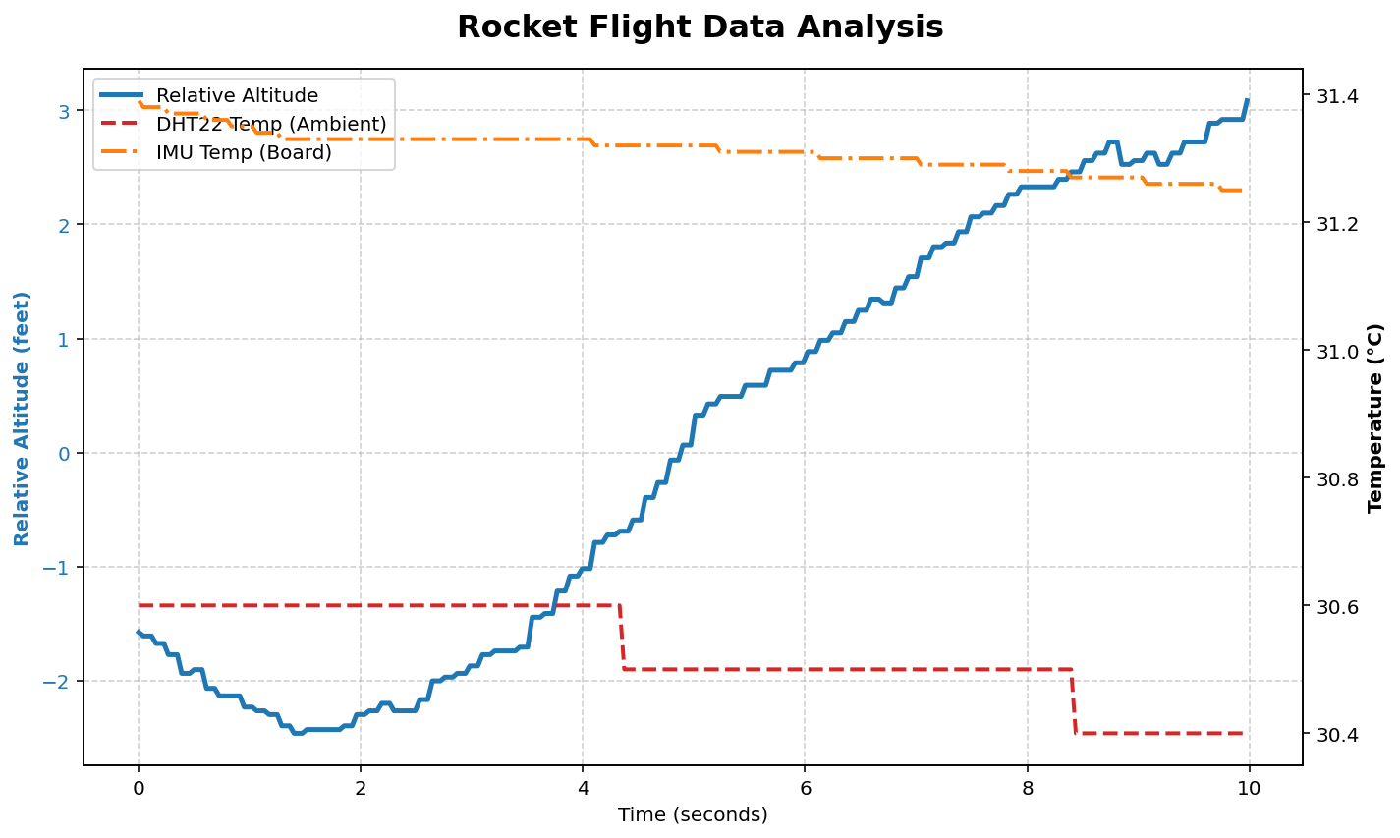
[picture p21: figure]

Example code of altitude time graph in feet, data taken from sd card and plotted using python matplotlib

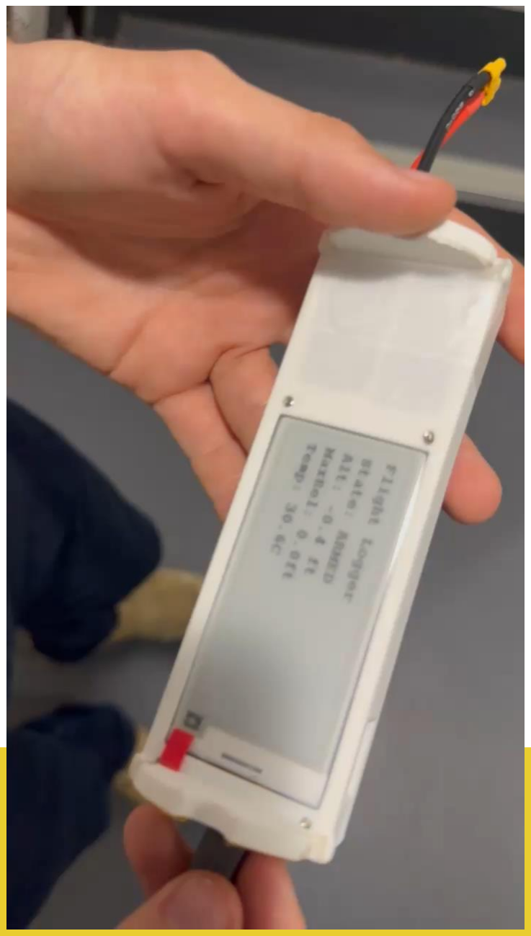
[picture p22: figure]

# Rideshare Payload Code

NRC RS-MRD-RPD-006 | Rev: A
NRC RS-MRD-RPD-004 | Rev: A
NRC RS-MRD-RPD-002 | Rev: A

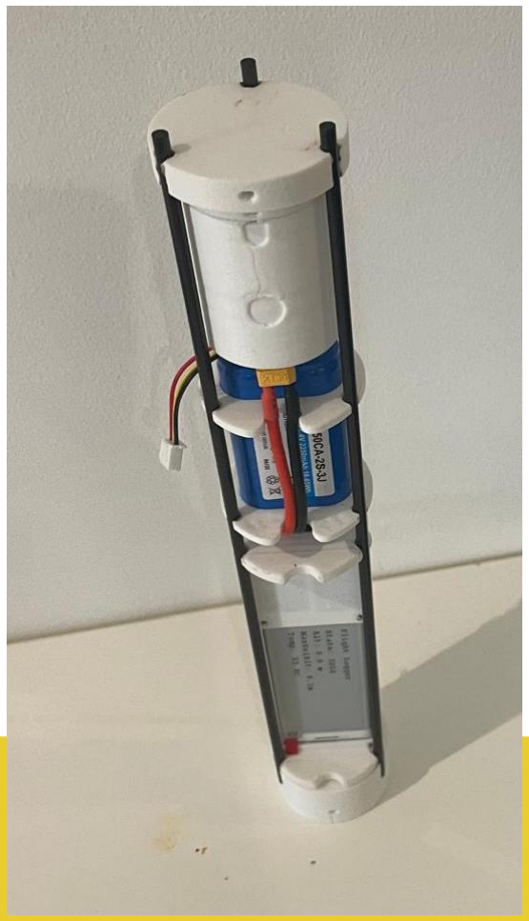
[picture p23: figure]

# Rideshare Payload Tests

# The Customer’s Payload

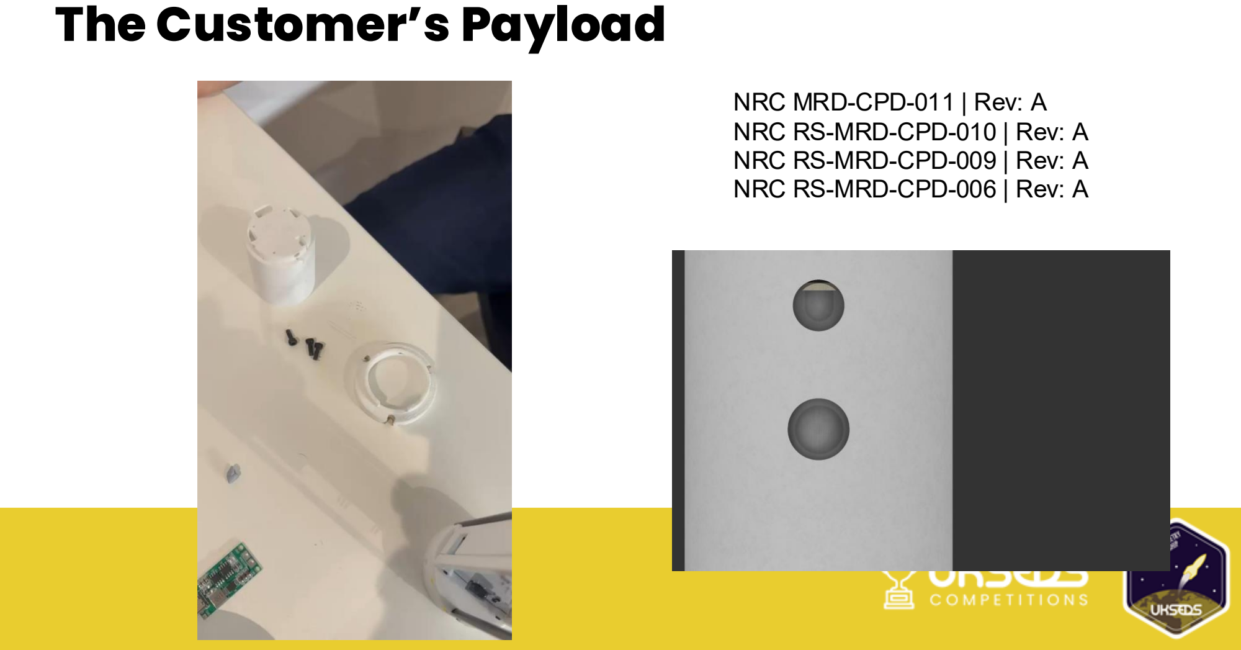
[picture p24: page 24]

NRC MRD-CPD-011 | Rev: A
NRC RS-MRD-CPD-010 | Rev: A
NRC RS-MRD-CPD-009 | Rev: A
NRC RS-MRD-CPD-006 | Rev: A

# The Customer’s Payload

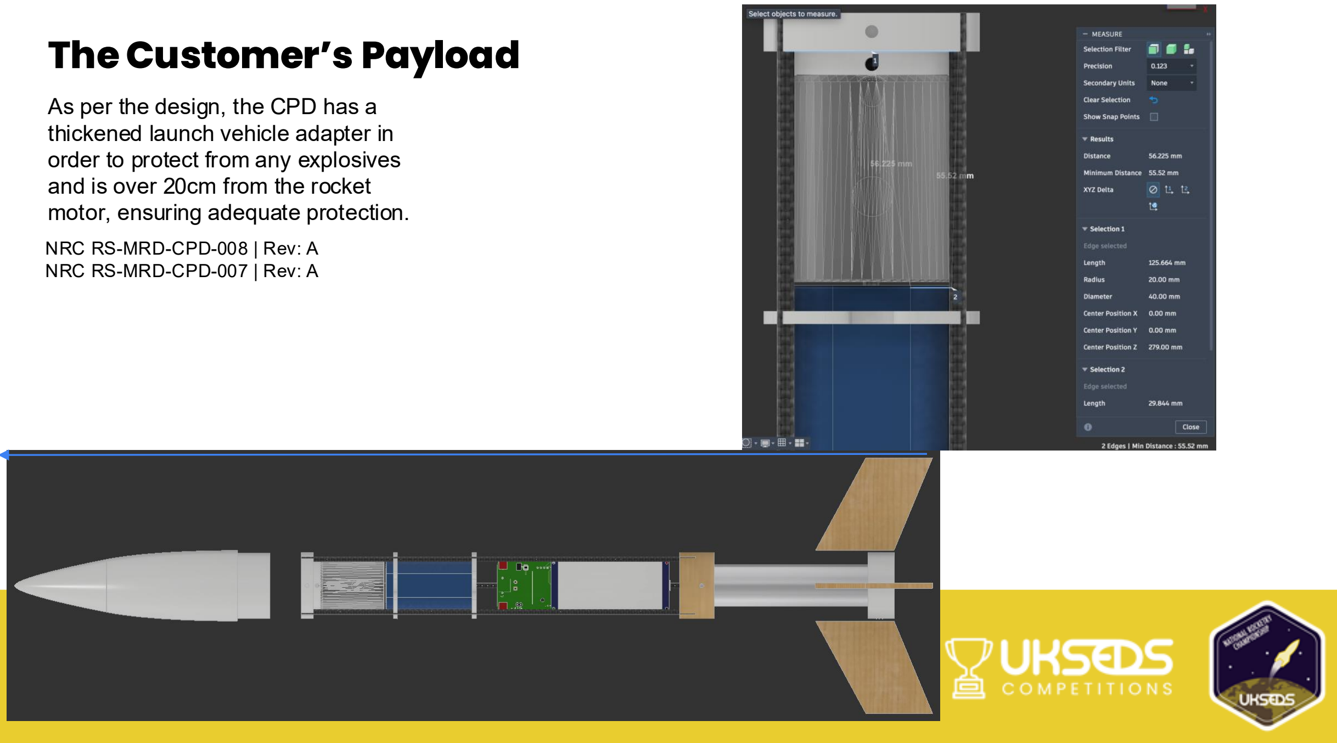
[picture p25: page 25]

NRC RS-MRD-CPD-008 | Rev: A
NRC RS-MRD-CPD-007 | Rev: A

As per the design, the CPD has a thickened launch vehicle adapter in order to protect from any explosives and is over 20cm from the rocket motor, ensuring adequate protection.

# The Customer’s Payload

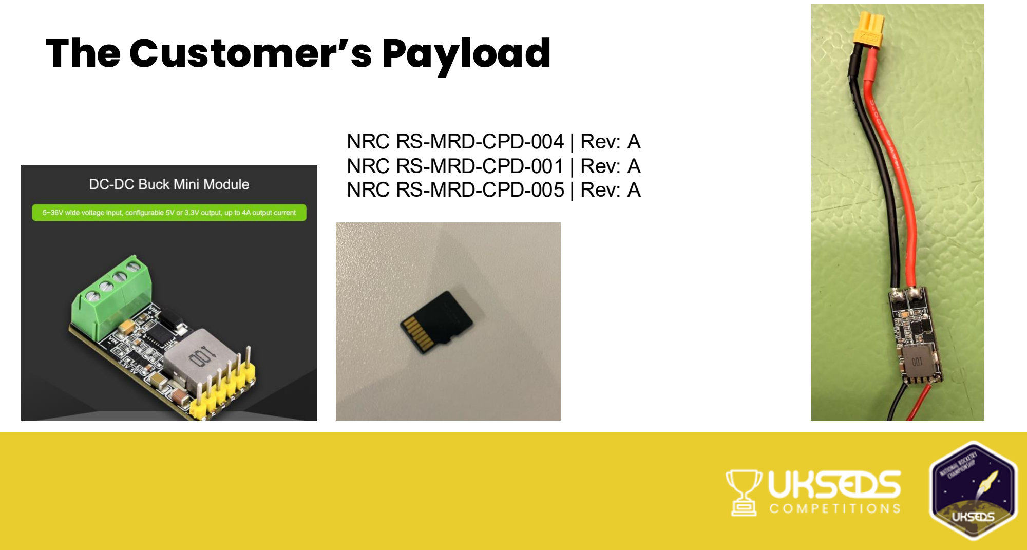
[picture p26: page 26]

NRC RS-MRD-CPD-004 | Rev: A
NRC RS-MRD-CPD-001 | Rev: A
NRC RS-MRD-CPD-005 | Rev: A

# Competition Day Procedure

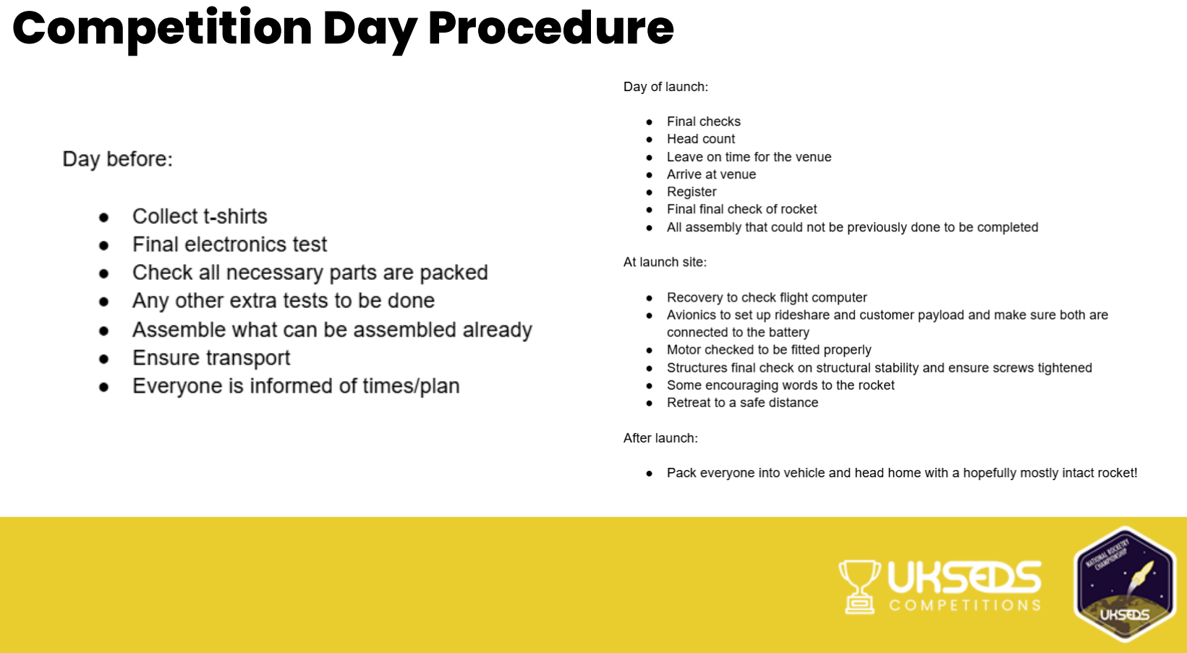
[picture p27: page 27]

# End Slide

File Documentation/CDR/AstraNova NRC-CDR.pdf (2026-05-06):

### UKSEDS National Rocketry Championship 2025-26

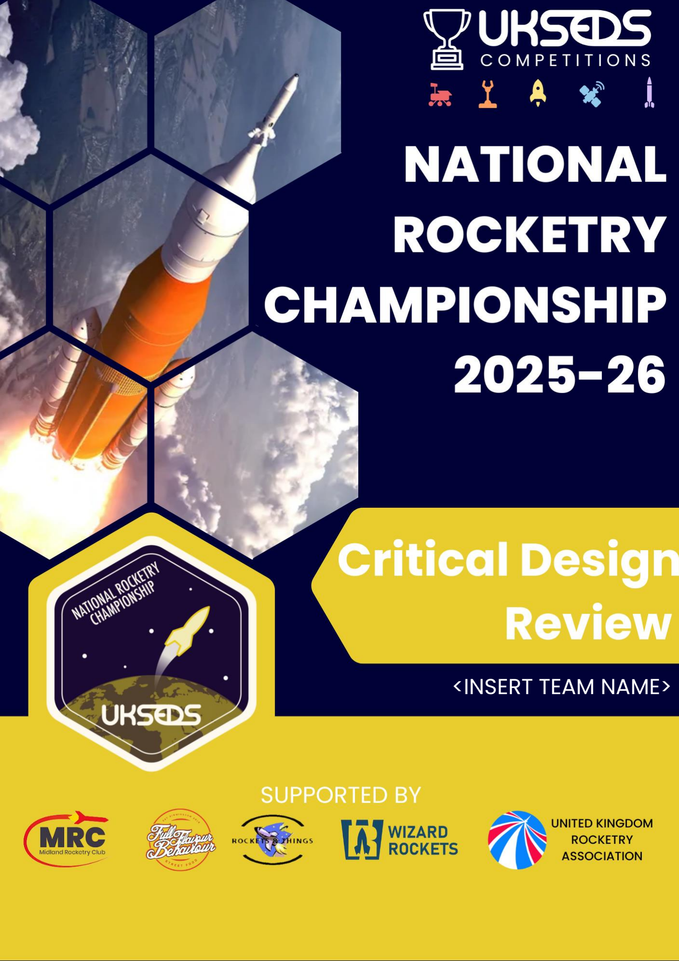
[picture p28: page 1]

NRC-CDR-001 Critical Design Review

# <INSERT TEAM NAME>

NRC-CDR-001 Critical Design Review

# UKSEDS National Rocketry Championship Critical Design Review

2025 - 2026

# UKC AstraNova

### Issued by (Project Lead): Cara Hefer

### University: University of Kent

## Table of Contents

1. Introduction | 5
1.1. Mission Statement | 5

NRC-CDR-001 Critical Design Review

1.2. | Objectives | 6
2. Project Management | 6
2.1 Team Members | 6
2.2 Financial Budget | 7
2.3 Project Risks and Mitigations | 7
2.4 Project Plan | 9
2.5 Work Breakdown Structure | 9
3. Preliminary Concept | 9
3.1. | Launch Vehicle | 9
3.1.1. Launch Vehicle Overview | 10
3.1.2. Concept Of Operations (CONOPS) | 11
3.1.3. OpenRocket Simulation | 11
3.1.4. Recovery System Design | 15
3.1.5. Launch Vehicle Components | 17
3.2. | Rideshare Payload | 18
3.2.1. General Overview | 19
3.2.2. | PCB Schematics | 21
3.2.3. | System Integration | 22
4. Systems Engineering | 23
4.1 Requirement Compliance Analysis | 23
4.2 Budgets | 27
5. Manufacturing Processes | 27
5.1 Launch Vehicle | 27
5.2 Rideshare Payload | 28
5.3 Issues and Solutions | 28
6. Testing | 28
6.1 Test Matrix | 28
6.2 Test Results | 29
7. Final Design | 29
7.1 Design Changes | 29

NRC-CDR-001 Critical Design Review

7.2 Improvements and Future Work | 30
8. Acknowledgements | 31
9. References | 31

### 1. Introduction

UKC AstraNova is a rocketry team from the University of Kent. We’re building a rocket for the UKSEDS National Rocketry Championship with the goal of reaching 670 m, carrying both a customer payload and our own payload, and landing safely within 1 km of the launch site.

The team is made up of students covering propulsion, structures, avionics, recovery, payload, and systems:

1. Cara-Alexandra Hefer – Team Lead / Systems
2. Brittany Nsongo – Vice Team Lead / Structures
3. Alexander Barry Dee – Propulsion
4. Arda Aydinlar – Systems
5. Theodoros Zilios – Recovery
6. Adam McGrath – Recovery
7. Calum Lewis – Avionics
8. Jack Oliver Shorey – Propulsion
9. Lucian Willcock – Payload
10. Robert Charles Langley Parry – Structures

The rocket is designed to reach the target altitude, deploy both payloads, and come back down safely using a controlled recovery system.

### 1.1. Mission Statement

To design, build, and fly a rocket that reaches 670 m, delivers its payloads successfully, and lands safely within the recovery zone.

### 1.2. Objectives

Launch the rocket to a target altitude of 670 m.
Successfully deploy the recovery system.
Recover the rocket safely within 1 km of the launch site.

NRC-CDR-001 Critical Design Review

Recover both the customer payload and team payload intact. Successfully record and recover flight data from the avionics system. Verify stable flight and controlled descent throughout the mission. Ensure all systems pass ground testing before launch.
Recover the rocket in a reusable condition where possible.
Complete the flight in full compliance with UKSEDS NRC safety rules.

### 2. Project Management

### 2.1 Team Members

Name | Role | Year/Course
Cara-Alexandra Hefer | Team Lead/Systems Engineer | 1 st Year/Astronomy, Space Science and Astrophysics
Brittany Nsongo | Vice Team Lead/Structural Engineer | 1st Year/Astronomy, Space Science and Astrophysics
Alexander Barry Dee | Propulsion Engineer | 2 nd Year/Physics with Astrophysics
Arda Aydinlar | Systems Engineer | 2 nd Year/Physics with Astrophysics
Theodoros Zilios | Recovery Technician | 1 st Year/Mechanical Engineering
Adam McGrath | Recovery Technician | 2 nd Year/Physics
Calum Lewis | Avionics Engineer | 2 nd Year/Electrical and Electronic Engineering
Jack Oliver Shorey | Propulsion Engineer | 4 th Year/Physics with Astrophysics
Lucian Willcock | Payload Specialist | 1 st Year/Physics with Astrophysics
Robert Charles Langley Parry | Structural Engineer | 2 nd Year/Ecology and Conservation

Figure 1: Table of Team Members

NRC-CDR-001 Critical Design Review

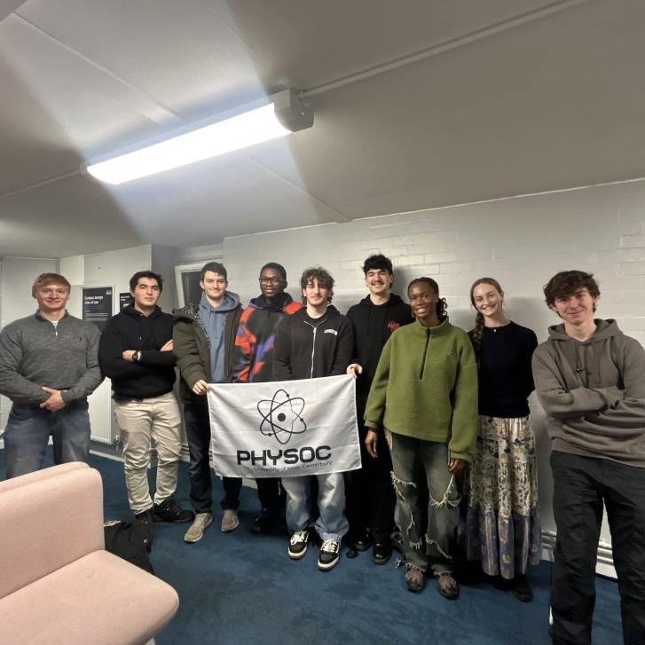
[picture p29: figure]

Figure 2: Image of Team Members

### 2.2 Financial Budget

We have been allocated a budget of £500 for this competition. Our current and future expenses are in a neat table format as follows:
Name | Amount
2 x BMFA membership | £102.00
Motor | £30.00
Shock cords | £25.00
Parachute | £35.00
PCB Design | £60.00
Extra Funds (in case) | £100.00
Total | £352.00
Figure 3: Table of Budget

### 2.3 Project Risks and Mitigations

Identify the major risks associated with your project and rocket design, and how you expect to manage these in the build-up to Launch Day.
Risk | Impact | Mitigation
Motor failure or underperformance | Rocket fails to reach target | Use manufacturer-certified motors only, follow motor storage and handling

NRC-CDR-001 Critical Design Review

| altitude or becomes unstable | guidelines, and select motor based on simulation and safety margins
Recovery system failure | Rocket impacts at high speed and is damaged or lost | Ground-test ejection charges, use redundant deployment methods where possible, pack parachutes carefully, and perform full recovery system checks before launch
Avionics failure (no data or no deployment trigger) | Loss of flight data and/or recovery system not triggered | Bench-test avionics, perform vibration and continuity checks, carry spare components, and use simple, proven deployment logic
Structural failure during ascent | Rocket breaks apart in flight | Use safety factors in structural design, test joints and airframe sections on the ground, and inspect for damage after every test
Stability issues (poor CG/CP margin) | Rocket becomes unstable or unsafe in flight | Simulate flight in OpenRocket, verify centre of gravity with motor and payload installed, and perform swing or rail tests
Payload damage or detachment | Loss of customer payload or data | Secure payload with mechanical restraints, test payload bay under vibration, and include padding or shock isolation
Landing outside recovery zone | Rocket lost or hard to retrieve | Tune descent rate, choose appropriate parachute size, track descent using beeper/GPS if allowed, and account for wind conditions
Human error during assembly | Miswiring or incorrect installation | Use checklists, peer-check critical steps, and perform final pre-launch inspections
Limited testing opportunities | Design issues not caught before competition | Do extensive ground testing on campus, subsystem tests (ejection, avionics, fit checks), and dry runs of full assembly

NRC-CDR-001 Critical Design Review

On-campus build/testing constraints | Incomplete testing of full system | Focus on safe subsystem testing indoors (avionics, recovery packing, structural fits) and document all procedures clearly
Schedule slip / team availability | Rushed build or missed deadlines | Set internal deadlines, assign clear subsystem owners, and hold regular progress checks
Weather on launch day | Unsafe launch or drift out of recovery zone | Prepare multiple parachute sizes if allowed, plan for wind limits, and be ready to scrub or adjust configuration

Figure 4: Table of Risk Assessment

### 2.4 Project Plan

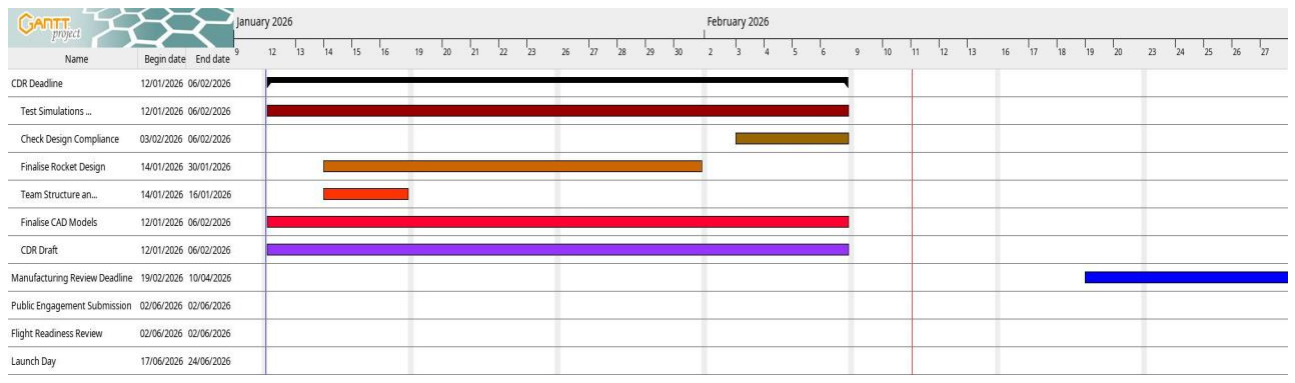
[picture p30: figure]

Figure 5: Image of Gantt Chart

### 2.5 Work Breakdown Structure

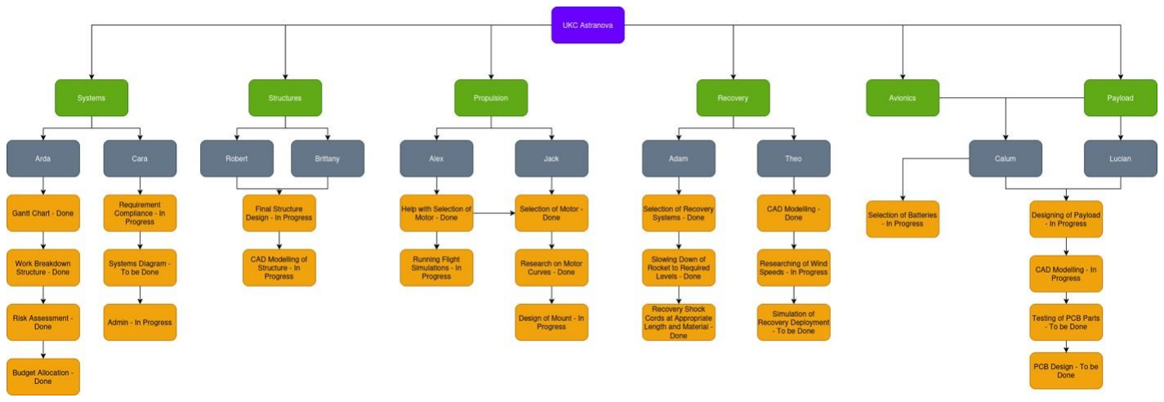
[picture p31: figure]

Figure 6: Image of Work Breakdown Structure

### 3. Preliminary Concept

### 3.1. Launch Vehicle

NRC-CDR-001 Critical Design Review

### 3.1.1. Launch Vehicle Overview


Figure 7: Diagram of Rocket Design The rocket uses a 4-fin design which are fixed at the bottom of the launch vehicle (NRC RS-TSN-SAR-001). They use a trapezoidal shape. They are made of spruce wood and have an aerofoil cross-section (NRC RS-TSN-SAR-002 & NRC RS-TSN-SAR-003). The motor (NRC RS-MRD-MIS-004) is secured by a 3D-printed tube which will hold the motor in place and will be secured using 5mm screws to the main body (NRC RS-TSN-MOR-001). The tube will also act as a bulkhead between the motor and the avionics compartment.
The payloads are secured in one large 3D printed part, containing the customer's payload at the bottom, the rideshare payload (NRC RS-MRD-MIS-007) at the top, and batteries stored in the middle.
The main body is made using balsa wood veneers fixed using wood adhesives (NRC RS-TSN-SAR-004). The internal width of 5cm and a thickness of 0.5cm. It has a length of 40cm.
The nosecone while be designed using 3D CAD and printed using lightweight plastic filament. The nose cone uses an Ogive shape. It will be held to the main body using a tight-fitting shoulder design.
The recovery system will be held separate from the avionics and stored partly in the nose cone (NRC RS-TSN-RRS-001).
The total length of the rocket is 59.9cm, and a total weight of 955g.

NRC-CDR-001 Critical Design Review

### 3.1.2. Concept Of Operations (CONOPS)


Figure 8: Diagram of Order of Operations.

### 3.1.3. OpenRocket Simulation


Figure 9: Annotated diagram of our design in OpenRocket. Flight simulations were carried out using OpenRocket 24.12, as required by UKSEDS, to estimate the vehicle’s ascent, stability throughout the flight, and recovery behaviour. The model included the final rocket structure provided by the structures team, measured mass properties, and the manufacturer-provided thrust curve for the selected motor, the Pro29 108G68-13A from Cesaroni Technology. Simulations were run using a 2 metre launch rod to match the expected launch setup. A windspeed of 0 m/s was used to isolate propulsion-driven vehicle behaviour, and additional wind cases, 10 m/s and 15 m/s, were analyzed to assess drift and recovery constraints. The

NRC-CDR-001 Critical Design Review

results were used to verify that the vehicle meets altitude, stability, and landing requirements.


Figure 10: Graph showing altitude against time for the rocket’s ascent and descent with no wind effects.
Figure 10 shows the simulated altitude versus time graph under 0 m/s wind conditions. The vehicle experiences a rapid increase in altitude during the motor burn phase, reaching burnout at approximately 2 seconds. This matches the manufacturer-provided thrust curve given. Following burnout, the rocket enters a coast phase where vertical velocity gradually decreases due to gravity and drag. Apogee occurs at approximately 10 seconds at a maximum altitude of roughly 470 metres. This equates to ~1540 ft, while this does not reach the maximum 2200 ft, it obtains many of the marks awarded for altitude while not going over the required distance. This satisfies the requirements NRC RS-MRD-MIS-001, NRC RS-MRD-MIS-002, and NRC RS-MRD-MIS-003. Recovery deployment is triggered at apogee, resulting in a smooth transition to descent. The nearly linear descent profile indicates a stable parachute deployment and a consistent descent rate until landing at approximately 58 seconds. The predicted apogee remains within the required altitude constraints and demonstrates that the selected propulsion system achieves the intended performance expected.

NRC-CDR-001 Critical Design Review


Figure 11: Graph showing stability against time for the rocket’s ascent and descent with no wind effects.
Figure 11 shows the simulated stability margin versus time graph under 0 m/s wind conditions. At ignition, the vehicle has a stability margin of approximately 2.3 calibres, increasing slightly during motor burn as propellant mass decreases. Throughout powered ascent and coast, the stability margin remains within 2.3-2.5 calibres, satisfying the minimum stability requirement, NRC RS-TSN-SMN-003, and indicating a consistently stable design. No significant reductions in stability are observed during the burn phase, demonstrating that the centre of gravity shift does not compromise vehicle stability. Following recovery deployment at apogee, the stability margin becomes negative as the vehicle transitions to parachute descent; this behaviour is expected and does not impact ascent stability performance.
For the drift constraints we simulated the data using wind speeds of 10 m/s and 15 m/s and compared the historic values of windspeed in the area which we got through visualcrossing.com [1], these values are the average wind speeds that have occurred on the two launch dates (5.4m/s on the 11th and 4 m/s on the 18th of June) from the past 10 years. this was to get an idea for the likelihood of each outcome. wind direction has been set to 180 deg from 90 deg for better graph clarity.

NRC-CDR-001 Critical Design Review


Figure 12: Graph showing displacement from launch with 15 m/s wind speeds. Figure 12 shows the graph of the rocket’s longitudinal and lateral displacement against altitude when the windspeed is at 15m/s. In this case the rocket lands 278.1 meters north and 0.25m west from the launch position which is well within the bounds of the requirements. However, the rocket lands with a speed of 17.4 m/s which is above the required landing speed however we chose to overrule this since windspeeds of 15m/s is an extreme and unlikely case.

NRC-CDR-001 Critical Design Review


Figure 13: Graph showing displacement from launch with 10 m/s wind speeds. Figure 13 shows the graph the graph of the rocket’s longitudinal and lateral displacement against altitude when the windspeed is at 10m/s. here the rocket lands 128.26m north and 0.28 m west from the landing position which is also within the bounds of the requirements; but this time the rocket lands of 13.3 m/s which is in the bounds of the requirements
In both cases the parachute ejects at a speed of 27.7 m/s due to the extreme wind changing the trajectory of the rocket to be flatter and causing the parachute, which is set to eject at apogee, to eject when the rocket is moving horizontally. However, both cases seem very unlikely.

### 3.1.4. Recovery System Design

The | type | of | recovery | system:
The recovery system to be used will be the TAC-24 parachute from Giant Leap (NRC RS-TSN-RRS-001). This parachute has been tested in OpenRocket to ensure that it will slow the rocket down to the required amount, >15m/s, and this is shown in our weight / descent graph (NRC RS-TSN-RRS-002 , NRC RS-TSN-RRS-003).

NRC-CDR-001 Critical Design Review


Figure 14: Weight Descent graph To aid this we will being using a commercial flight computer (NRC RS-TSN-RRS-004) to record and compute the necessary calculations needed to determine when the recovery will be triggered.
Shock cords made of Kevlar and will be sued to make sure that no piece of the rocket is detached when the recovery is deployed and all cords will be the appropriate length of over 2m (NRC RS-TSN-RRS-007 , NRC RS-TSN-RRS-008).
All electronics related to the recovery system will be isolated from the rest of the rocket (NRC RS-TSN-RRS-005).
Tilt switches will not be used in the design of the recovery system as all calculations will be done by the flight computer (NRC RS-TSN-RRS-006).
How recovery is detected:

Recovery deployment will be controlled by a Mercury V1 altimeter and flight computer which will be disabled until the rocket is being prepared for launch (NRC RS-TSN-RRS-007). This device uses barometric pressure sensing and onboard accelerometers to determine key flight parameters, including altitude, vertical velocity, and acceleration. [2]

Apogee will be detected when the flight computer identifies a transition from positive to negative vertical velocity. Upon confirming apogee, the altimeter will trigger the primary ejection charge to initiate recovery deployment. The system will be configured and calibrated prior to launch to ensure accurate pressure readings and reliable apogee detection.

NRC-CDR-001 Critical Design Review

How recovery is triggered:

Recovery will be initiated at apogee and controlled by the flight computer. The onboard flight computer will detect apogee using barometric and/or accelerometer data and trigger deployment of the recovery system.

At apogee, an ejection charge will fire to separate the nose cone from the airframe, allowing the parachute to deploy safely from the forward section of the rocket. The separation event will be controlled by the avionics system to ensure deployment occurs at the correct flight phase (NRC RS-TSN-RRS-005).

Shock cords will connect the nose cone and main airframe to prevent complete separation after deployment. These will be sized appropriately to withstand deployment loads and reduce the risk of structural damage (NRC RS-TSN-RRS-008).

### 3.1.5. Launch Vehicle Components

The motor selected to deliver thrust for the rocket was the Cesaroni Technology Pro29 108G68-13A. This rocket provides a total impulse of 107.8 newton seconds of thrust with a burn time of 1.61 seconds [3]. This motor falls within the regulation outlined by UKSEDs of having an impulse of less than 130 newton seconds as well as being a 2 grain, 29 millimetre motor [NRC RS-MRD-MIS-004]. It was selected due to its constant in flight thrust, providing a stable and steady burn throughout the duration of the flight without any sudden increases or decreases in thrust as seen by the graph in the figure below [4]. This constant thrust is hypothesised to provide more stability in flight due to the lack of any sudden changes during the main burn phase, as well as providing extra thrust at the beginning of the burn in order to accelerate the rocket to 20 metres per second before it leaves the launch rail. With the current design of the rocket, this motor will be able to provide enough thrust to propel the rocket to an apogee of roughly 470 metres.

NRC-CDR-001 Critical Design Review


Figure 15: Manufacturer-provided thrust curve. The motor mount, as seen in the figure below, was designed to accommodate the motor whilst minimising weight. The topmost part of the mount will be screwed into the fuselage (using metal screws) to ensure a secure connection between the motor, mount and the body of the rocket is achieved. The motor will then be placed into the centre of top piece of the mount, and the bottom piece will be threaded on to the top piece using the designed threads. Once threaded on, the bottom will also be screwed to the fuselage. This design will not only effectively secure the motor, but also allow for quick, easy access to the motor and reduce the weight of the mount when compared to other designs.


Figure 16: DIagram of Motor Mount
3.2. Rideshare Payload

NRC-CDR-001 Critical Design Review

3.2.1. General Overview

The rideshare payload is a competition-specific avionics system designed to:
- Measure launch vehicle altitude
- Log altitude vs time data
- Display apogee onboard
- Record and log additional independent sensor data The system consists of:
- Custom-designed PCB (NRC 2025–26 specific)
- Raspberry Pi Pico 2 (SMD mounted)


Figure 17: Raspberry Pi Pico 2

- Waveshare 10DOF IMU (Version D, barometer-based altitude inlcuded as potential separate sensor)


- Figure 18: Waveshare IMU
- Waveshare e-paper display

NRC-CDR-001 Critical Design Review


Figure 19: E-paper Display
- microSD storage, Figure 10 was used as a reference


Figure 20: Sd card Reader
- DHT22 temperature sensor


Figure 21: DHT22 Sensor
- Shared 7.4 V 2.25 Ah 2S Li-ion battery
- External arming switch
Altitude is measured using the integrated barometer at 50 Hz, avoiding inertial drift (RS-MRD-RPD-002).
Apogee is computed onboard and displayed on the e-paper display. E-paper retains its last state without power, ensuring compliance with RS-MRD-RPD-004.
Altitude and timestamp data are written directly to microSD in CSV format. An altitude vs time plot (feet vs seconds) can be produced within 10 minutes of recovery (RS-MRD-RPD-003).

NRC-CDR-001 Critical Design Review

Additional recorded data, which should be written to the MicroSD (independent of altitude sensor) includes acceleration, gyroscope, magnetometer and temperature data, satisfying RS-MRD-RPD-006.
The PCB includes a silkscreened team logo (RS-MRD-RPD-005).
Estimated rideshare mass: ~100 g (50 g PCB + 50 g sled).
3.2.2. PCB Schematics
A dedicated PCB has been designed from scratch for this competition (complying with RS-MRD-RPD-001).


Figure 22: PCB Schematic
Integrated subsystems:
- Raspberry Pi Pico 2 (SMD pads)
- 4 A-rated buck converter (5 V Customer Payload supply)
- LDO regulator for rideshare electronics
- I²C bus for IMU and DHT22
- SPI bus for e-paper and microSD
- Decoupling and required pull-ups Power architecture:

NRC-CDR-001 Critical Design Review

7.4 | V | battery | → | 5 | V | buck | (Customer | Payload)
7.4 V battery → LDO → Rideshare electronics
The buck converter exceeds the 1.5 A maximum Customer Payload requirement (RS-MRD-CPD-003), providing margin.
3.2.3. System Integration
Mechanical
Payload bay internal diameter: 50 mm, exceeding the 40 mm minimum (RS-MRD-CPD-007).
The official UKSEDS Launch Vehicle adapter interface geometry remains unmodified (RS-MRD-CPD-006).
The thrust axis passes centrally through the Customer Payload (RS-MRD-CPD-008).
The payload bay is unpressurised for barometric operation (RS-MRD-CPD-010).
Three M3 bolts are provided for mounting (RS-MRD-CPD-011).
Electronics are mounted on a removable 3D-printed avionics sled to:
- Improve vibration resistance
- Allow rapid access
- Provide cable strain relief
External arming switch for the battery to be added to cut down time needed on the Launchpad to prepare the Rocket. Another thing done to cut down time, is to add an avionics sled with a twist lock mechanism, to quickly be able to take the payloads in and out of the rocket faster, meaning less time on the pad before and after the flight.
Electrical
Customer Payload is powered via a regulated 5 V bus through a female XT30 connector (RS-MRD-CPD-004).
Battery | | | | | | | | capacity:
7.4 V × 2.25 Ah = 16.65 Wh
Customer | Payload | requirement | (45 | min):
7.5 W × 0.75 h = 5.63 Wh

NRC-CDR-001 Critical Design Review

Estimated | rideshare | consumption: | ~1 | W
Total required ≈ 6.4 Wh
Energy margin >2.5× (RS-MRD-CPD-002, RS-TSN-ESS-001).
External arming switch allows system activation without disassembly (RS-TSN-ESS-002).
All wiring is multi-core stranded (RS-TSN-ESS-003).
Recovery is handled by a Mercury V1 flight computer with an independent battery, ensuring electrical isolation.

### 4. Systems Engineering

### 4.1 Requirement Compliance Analysis

Requirement ID | Met? [Yes, No, Partially] | Rational
NRC RS-TSN-MOR-001 | Yes | The motor mount will transfer thrust being secured to both the body and the motor, allowing for minimal vibrations and prevention of slipping.
NRC RS-TSN-MOR-002 | Partially | This is to be tested once we have all the parts
NRC RS-TSN-MOR-003 | Partially | This is to be tested once we have all the parts
NRC RS-TSN-SMN-001 | No | The rocket achieves a launch speed of 17m/s off the rail
NRC RS-TSN-SMN-003 | Yes | The rocket has been designed to maintain a stability margin between 1.87 and 2.5 during all stages of flight
NRC RS-TSN-SAR-001 | Partially | The fins are designed to stay in line with the rockets longitudinal axis but has yet to be constructed

NRC-CDR-001 Critical Design Review

NRC RS-TSN-SAR-002 | Partially | To be tested once we have the parts
NRC RS-TSN-SAR-003 | Partially | To be tested once we have the parts
NRC RS-TSN-SAR-004 | Partially | To be tested once we have the parts
NRC RS-TSN-SAR-005 | Yes | We are not using interconnected tubes in our design for the main body
NRC RS-TSN-SAR-006 | Partially | To be tested once we have all the parts
NRC RS-TSN-SAR-007 | Yes | Two rail guides are included in the main body of the launch vehicle
NRC RS-TSN-SAR-008 | Yes | Finite Element Analysis was not used to select or test materials
NRC RS-TSN-ESS-001 | Yes | The power of the battery to be used will be capable of supporting this.
NRC RS-TSN-ESS-002 | Partially | This has not been tested; however, that is the theoretical expectation.
NRC RS-TSN-ESS-003 | Yes | A multi-core wire has been included in the design
NRC RS-TSN-ESS-004 | No | We’re not communicating with the rocket wirelessly
NRC RS-TSN-RRS-001 | Yes | Parachute to be used: Spherachute plus+ W/swivel 24’’. This has been simulated on OpenRocket.
NRC RS-TSN-RRS-002 | Yes | OpenRocket simulation shows the system shall reduce the speed to 9.5m/s
NRC RS-TSN-RRS-003 | Partially | Research is being done to estimate this

NRC-CDR-001 Critical Design Review

NRC RS-TSN-RRS-004 | Yes | The Mercury V1 is UKRA approved.
NRC RS-TSN-RRS-005 | Yes | A bulkhead is in between recovery system and electrical system
NRC RS-TSN-RRS-006 | Yes | Flight computer is being used
NRC RS-TSN-RRS-007 | Partially | Uncertainty of this for the moment. Awaiting part to confirm.
NRC RS-TSN-RRS-008 | Yes | Holes to be created in the nozzle to secure the eye bolts using the nut.
NRC RS-TSN-RRS-007 | Yes | We have a role of shock cords to customize the size
NRC RS-TSN-RRS-008 | Yes | They’re kevlar.
NRC RS-MRD-MIS-001 | No | The OpenRocket simulation reached an apogee of 470m.
NRC RS-MRD-MIS-002 | No | We don’t reach beyond the target height.
NRC RS-MRD-MIS-003 | Partially | To be tested
NRC RS-MRD-MIS-004 | Yes | Motor fits in the guidelines
NRC RS-MRD-MIS-005 | Yes | It’s been purchased through UKSEDs
NRC RS-MRD-MIS-006 | Yes | The motor form was submitted
NRC RS-MRD-MIS-007 | Partially | Unable to determine weight at the moment due to delays in shipment

NRC-CDR-001 Critical Design Review

NRC RS-MRD-MIS-008 | Partially | To be tested
NRC RS-MRD-CPD-001 | Yes | 5V is being used
NRC RS-MRD-CPD-002 | Yes | The power of the battery supports the system for approximately 1 hour 30 minutes
NRC RS-MRD-CPD-003 | Yes | Current of 1.5 amps will power the Customers Payload.
NRC RS-MRD-CPD-004 | Partially | Due to unclear weight, position of the port is undecided.
NRC RS-MRD-CPD-005 | Yes | Provided by the launch service
NRC RS-MRD-CPD-006 | Partially | Adapters are designed and printed. Once position of port is decided, the right adapter will be chosen.
NRC RS-MRD-CPD-007 | Yes | Payload bay has measurements are 45mm diameter and 53mm length.
NRC RS-MRD-CPD-008 | Yes | Design of rocket and integrated payload accounts for this
NRC RS-MRD-CPD-009 | Partially | Design is still being discussed to figure out how this will be achieved.
NRC RS-MRD-CPD-010 | Yes | Theres a hole in the rocket for the camera.
NRC RS-MRD-CPD-011 | Partially | Awaiting the arrival of the bolts
NRC RS-MRD-RPD-001 | Partially | Testing uncomplete, awaiting parts
NRC RS-MRD-RPD-002 | Yes | Using the barometer on a 10dof IMU

NRC-CDR-001 Critical Design Review

NRC RS-MRD-RPD-003 | Partially | Parts are delayed and programming still needs to be done
NRC RS-MRD-RPD-004 | Partially | Parts are delayed and programming still needs to be done
NRC RS-MRD-RPD-005 | Partially | To be printed
NRC RS-MRD-RPD-006 | Yes | Multiple sensor included in the rocket. Still deciding shall be used for this part of the requirement.

Figure 23: Table of NRC Requirements

### 4.2 Budgets

Mass Budget

Subsystem | Component | Estimated mass (g) | Margin | Notes
Propulsion | Cesaroni Pro29 108G68 | 120 | - | Manufacturer value
| Motor mount + hardware | 80 | 10% | 3D printed + screws
Structures | Main airframe (balsa tube) | 200 | 15% | Veneer construction
| Spruce fins (x4) | 120 | 15% | Aerofoil shaped
| Bulkheads / couplers | 60 | 10% | plywood / printed
| Nosecone (PLA) | 80 | 10% | 3D printed
Recovery | 24” parachute | 70 | 10% | Spherachute
| Shock cords (kevlar) | 40 | 10% | >2m
| Ejection charge hardware | 20 | 10% | Charge wells, fittings

NRC-CDR-001 Critical Design Review

Avionics | Mercury V1 altimeter | 25 | - | Manufacturer value
| Rideshare PCB + IMU + SD | 100 | - | Estimated
| Battery (7.4V 2.25Ah) | 140 | - | Li-ion pack
| Wiring + switches | 20 | 10% | Multi-core wiring
Payload | Customer Payload | 75 | Fixed | Competition defined
TOTAL | | 955g

Power Budget
Parameter | Value
Battery capacity | 16.65 Wh
Customer Payload | 5.63 Wh
Rideshare | ~0.75 Wh
Total required | ~6.4 Wh
Energy margin | >2.5×
Figure 24: Table of Power Budget

### 5. Manufacturing Processes

### 5.1 Launch Vehicle

- The main body will be produced using thin balsa wood veneers which will be wrapped around each other and fixed using wood adhesives to produce a fixed tube design with an internal width of 5cm and thickness of 0.5cm
- The fins will be cut from a large plank of spruce using a wood saw. Then they will be sanded down to produce an aerofoil cross-section with a maximum width of 0.5cm and measured using a calliper. It will be connected to the main body by sliding into cut-outs in the main body and secured using wood adhesives.
- The nosecone will be produced using PLA filaments in a 3D printed and secured to the main body using a tight-fitting shoulder, which will hold the nosecone in place.

### 5.2 Rideshare Payload

NRC-CDR-001 Critical Design Review

- PCB designed in CAD and fabricated externally with SMD assembly using PCBWay.
- Avionics sled manufactured via 3D printing.
- UKSEDS launch vehicle adapter 3D printed without modification to interface faces.
- Wiring strain-relieved and mechanically secured.

### 5.3 Issues and Solutions

Issue | Solution
Severe delay of parts for Payload | Created a provisional Circuit board with similar parts
Extremely high power requirement for Customers payload | Using a Buck converter instead of the planned Linear Voltage Regulator
Power outage could cause SD card to corrupt | Fram as a separate data storage
Slow preparation of rocket on Launchpad and slow data retrieval after landing due to payloads being difficult to remove. | Putting payloads in an avionics sled
Because of a larger rocket diameter, the FOV of the Camera on the Customers Payload would be severely impeded | A larger hole in the rocket to account for the cameras FOV

Figure 25: Table of Manufacturing Issues and Solutions

### 6. Testing

### 6.1 Test Matrix

There are many different test matrix table formats, but the chosen format should show all the tests you are planning to carry out and the corresponding requirements these tests are trying to verify/validate. See example. (https://1.bp.blogspot.com/-4eRmufFypck/Ty6KoT2R3-I/AAAAAAAAAHQ/bk_sl0e2M44/s1600/Requirement+Traceability+Matrix+%255BRTM%255D.PNG)
Test | Requirement
45 min runtime (by simulating a continuous load on the Battery) | CPD-002, ESS-001
5 V regulation under 1.5 A load (to be tested using lab supplies) | CPD-001, CPD-003
Altitude measurement validation ( lowering sensor from a high place with a string) | RPD-002
SD logging + plotting ( to be tested under different loads and refresh rates) | RPD-003

NRC-CDR-001 Critical Design Review

Apogee display retention ( by unplugging the power when displaying a value) | RPD-004
Mechanical integration (by testing if it fits the payload inside while fitting in the rocket) | CPD-007
External arming verification ( by testing a screw switch on the battery and if al the systems come online with switching it on) | ESS-002
Testing PCB components on a bread board, to make sure our PCB design works. | NRC RS-MRD-RPD-001
The parachute will have a 1kg weight attached to it to ensure that it works efficiently and will be able to support the weight of the rocket. | RRS-001
The mounting bracket will be tested by shaking the mount and observing its ability to negate any damage. | MOR-002, MOR-003
The fins will be tested by applying weights equal to the main body of the rocket from the tip chord edge longitudinally and laterally | SAR-002 & SAR-003
The main rocket body will be tested by suspending the main body from the centre of mass and applying a weight equal to the total weight of the rocket from the leading end of the main body | SAR-004

Figure 26: Test Matrix Table

### 6.2 Test Results

For Payloads and Avionics: (To be completed following hardware arrival and integration.) (due to severe delays.)

### 7. Final Design

### 7.1 Design Changes

NRC-CDR-001 Critical Design Review

The rocket design has been modified to achieve a stability margin between 1.75 and
2.50 calibres, in accordance with NRC RS-TSN-SMN-003 | Rev: A.

The changes implemented are outlined below:

- Main Body: The body material has been changed from cardboard to balsa wood veneers to reduce overall structural density.
- Nose Cone: The nose cone geometry has been redesigned to incorporate a shoulder that fits securely into the main body. The material has been changed from polystyrene to PLA, and the component will be manufactured using 3D printing.
- Fins: Both the dimensions and material of the fins have been revised. The material has been changed from plywood to spruce to maintain the required stability margin following the other structural modifications .

Payload Integration:

- Increased payload bay diameter to 50 mm
- Finalized 50 Hz sampling rate
- Selected 4 A-rated buck converter
- Confirmed shared 7.4 V 2.25 Ah battery architecture
- Confirmed electrical isolation of recovery system
- Implemented external arming switch

### 7.2 Improvements and Future Work

For Payload:
- Optional FRAM redundancy
- EMI shielding refinement
- Telemetry integration (subject to Ofcom compliance)

Working on getting a launch speed of 20m/s.

NRC-CDR-001 Critical Design Review

### 8. Acknowledgements

### 9. References

[1] Visual Crossing (2026) Visual Crossing weather data services. Available at: https://visualcrossing.com (Accessed: 16 February 2026).
[2] Model Rockets (no date) Mercury V1 Altimeter & Flight Logger Computer. Available at: https://modelrockets.co.uk/electronics-and-payloads/altimeters/mercury-v1-altimeter-and-flight-charts/ (https://modelrockets.co.uk/electronics-and-payloads/altimeters/mercury-v1-altimeter-and-flight-charts/) (Accessed: 16 February 2026).
[3] Cesaroni Technology Incorporated (no date) Pro29 108G68-13A motor. Available at: https://cesaroni.net/products/p29-2g/108g68-13a/ (Accessed: 16 February 2026).
[4] ThrustCurve.org (no date) Cesaroni 108G68-13A thrust curve. Available at: https://www.thrustcurve.org/motors/Cesaroni/108G68-13A/ (Accessed: 16 February 2026).
[5] Raspberry Pi Ltd (no date) Raspberry Pi Pico 2. Available at: https://www.raspberrypi.com/products/raspberry-pi-pico-2/ (Accessed: 16 February 2026).
[6] Waveshare (no date) 10 DOF IMU Sensor (Version D). Available at: https://www.waveshare.com/wiki/10_DOF_IMU_Sensor_(D) (Accessed: 16 February 2026).
[7] Waveshare (no date) 2.9 inch e-Paper module. Available at: https://www.waveshare.com/2.9inch-e-paper-module.htm (Accessed: 16 February 2026).
[8] Adafruit (no date) Adafruit micro-SD breakout board tutorial. Available at: https://learn.adafruit.com/adafruit-micro-sd-breakout-board-cardtutorial/introduction (https://learn.adafruit.com/adafruit-micro-sd-breakout-board-card-tutorial/introduction) (Accessed: 16 February 2026).
[9] Adafruit (no date) DHT22 temperature and humidity sensor (Product ID: 385). Available at: https://www.adafruit.com/product/385#technical-details (Accessed: 16 February 2026).

### Appendices

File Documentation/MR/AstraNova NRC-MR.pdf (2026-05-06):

# NATIONAL ROCKETRY CHAMPIONSHIP

# Manufacturing Review

# UKC AstraNova

# Cara-Alexandra Hefer Brittany Nsongo


# Alexander Barry Dee


# Arda Aydinlar Theodoros Zilios Adam McGrath Calum Lewis Jack Oliver Shorey Lucian Willcock Robert Charles Langley Parry

# Introduction


# - Our mission is to design, build, and fly a rocket that reaches 670 metres, delivers its

payloads successfully, and lands safely within the recovery zone.
- To achieve this, we aim to hit our target altitude with stable flight, deploy a reliable

# recovery system, and ensure the rocket is recovered within one kilometre of the launch site. We will also recover both payloads intact and successfully retrieve

flight data from our avionics system.
- Throughout the flight, we will maintain stability and a controlled descent, supported by thorough ground testing before launch.

# - Finally, we aim to recover the rocket in a reusable condition where possible, while

fully complying with UKSEDS NRC safety regulations.

# Project Plan


Reason | Amount
2 x BMFA membership | £102.00
Motor | £30.00
Shock cords | £ 25.00
Parachute | £35.00
Mouser Electronics | £78.88
CPC Farnell Avionics | £25.49
Bambulab ABS-GF Filament | £31.99
Wires/Cabling | £50.96
Humidity Sensor + MicroSD | £19.30
Total | £398.82

Subsystem | Component | Estimatedmass (g) | Margin | Notes
Propulsion | Cesaroni Pro29 108G68 | 120 | - | Manufacturer value
| Motor mount + hardware | 80 | 10% | 3D printed + screws
Structures | Main airframe (balsa tube) | 200 | 15% | Veneer construction
| Spruce fins (x4) | 120 | 15% | Aerofoil shaped
| Bulkheads / couplers | 60 | 10% | plywood / printed
| Nosecone (PLA) | 80 | 10% | 3D printed
Recovery | 24” parachute | 70 | 10% | Spherachute
| Shock cords (kevlar) | 40 | 10% | >2m
| Ejection charge hardware | 20 | 10% | Charge wells, fittings
Avionics | Mercury V1 altimeter | 25 | - | Manufacturer value
| Rideshare PCB + IMU + SD | 100 | - | Estimated
| Battery (7.4V 2.25Ah) | 140 | - | Li-ion pack
| Wiring + switches | 20 | 10% | Multi-core wiring
Payload | Customer Payload | 75 | Fixed | Competition defined
TOTAL | | 955g

Parameter | Value
Battery capacity | 16.65 Wh
Customer Payload | 5.63 Wh
Rideshare | ~0.75 Wh
Total required | ~6.4 Wh
Energy margin | >2.5×

# Launch Vehicle Manufacture

# Things to include: - Motor configuration and retainment - Recovery system configuration and assembly - Interface with customer payload

# - How is it secured - How is it powered: directly from battery over buck converter (XT30 connector at the bottom)(possibly a video) - How is it assembled? (demo video preferred)

# Recovery system configuration and assembly


- We will be connecting our parachute to shocks cords which will be tied to eye bolts that will be screwed into the main body of the rocket.
- We are using flash paper as our source of pressure for the ejection charge and this will be controlled and lighted by an igniter. In order to control when the ejection charge is activated, we will use a flight computer to detect when our rocket reaches apogee.

# - This follows the following guidelines:

# 5.1 Use of Recovery System 5.5 Flight Computer 5.6 Isolation of Recovery Circuit 5.8 Parachute Deployment 5.9 Detection of Apogee 5.10 Flight Computer Disarming Mechanism 5.11 Transmission of Recovery Shock Loads 5.12 Shock Cord


# Motor Mount

# - Initial Motor Mount Scrapped - New Design Created To Improve On Failures - Rivets To Hold It In Place

# - Testing:

# - Fixing to the rocket body - Vibration test - Compression stress test

# Interface with customer payload


# - How is it secured: the avionics sled will be secured to the bottom of

the payload bay with a bayonet mount, which is glued down.

# - How is it powered: directly from battery over buck converter (XT30


# connector at the bottom)

# - How is it assembled?: it is secured to an avionics sled with the launch vehicle adapter directly connected to it



# Launch Vehicle Simulation Data

# - The windspeed was set to 0 m/s and the launch rod was set to 2 m

when the simulations were ran.

# - The simulations now show that the rocket reaches the desired

apogee.

# - The stability margin caliber is between 1.75 and 2.5 as required

in 2.3.

Structures manufacturing • Completed production: o Main body bought and tested o Fins material changed and tested o Nose cone designed and 3d printed


# 4 fins produced using saw machines and made of MDF wood panels

Main body made

# from carboard tube

# Design did not flex under an applied weight of 1.5 kg suspended both laterally and longitudinally

# Design was able to support a 1.5kg weight without undergoing significant

(>10mm)

# deflection


# Rideshare Payload Manufacture

# - General plan and progress on manufacturing:

# - In final stages of design


# - Need to get traces double checked - Then will send it off to JLCPCB - We will then solder the parts our self

# Rideshare Payload Manufacture

# - PCB manufacture:


# Rideshare Payload Manufacture

# - Assembly of rideshare and customer payload: both are going to be connected to the avionics sled - We have tested individual parts of the PCB


# System Engineering

Requirement ID | Met? [Yes, No, Partially] | Rational
NRC RS-TSN-MOR-001 | Yes | The motor mount will transfer thrust being secured to both the body and the motor, allowing for minimal vibrations and prevention of slipping.
NRC RS-TSN-MOR-002 | Partially | This is to be tested once we have all the parts
NRC RS-TSN-MOR-003 | Partially | This is to be tested once we have all the parts
NRC RS-TSN-SMN-001 | Yes | The rocket achieves a launch speed of 19.9m/s off the rail
NRC RS-TSN-SMN-003 | Yes | The rocket has been designed to maintain a stability margin between 1.87 and 2.5 during all stages of flight
NRC RS-TSN-SAR-001 | Partially | To be tested
NRC RS-TSN-SAR-002 | Partially | To be tested
NRC RS-TSN-SAR-003 | Partially | To be tested
NRC RS-TSN-SAR-004 | Partially | To be tested
NRC RS-TSN-SAR-005 | Yes | We are not using interconnected tubes in our design for the main body
NRC RS-TSN-SAR-006 | Partially | To be tested once we have all the parts
NRC RS-TSN-SAR-007 | Yes | Two rail guides are included in the main body of the launch vehicle
NRC RS-TSN-SAR-008 | Yes | Finite Element Analysis was not used to select or test materials
NRC RS-TSN-ESS-001 | Yes | The power of the battery to be used will be capable of supporting this.
NRC RS-TSN-ESS-002 | Partially | This has not been tested; however, that is the theoretical expectation.
NRC RS-TSN-ESS-003 | Yes | A multi-core wire has been included in the design
NRC RS-TSN-ESS-004 | Yes | We’re not communicating with the rocket wirelessly


# System Engineering

NRC RS-TSN-RRS-001 | Yes | Parachute to be used: Spherachute plus+ W/swivel 24’’. This has been simulated on OpenRocket.
NRC RS-TSN-RRS-002 | Yes | OpenRocket simulation shows the system shall reduce the speed to 9.5m/s
NRC RS-TSN-RRS-003 | Partially | Research is being done to estimate this
NRC RS-TSN-RRS-004 | Yes | The Mercury V1 is UKRA approved.
NRC RS-TSN-RRS-005 | Yes | A bulkhead is in between recovery system and electrical system
NRC RS-TSN-RRS-006 | Yes | Flight computer is being used
NRC RS-TSN-RRS-007 | Partially | Uncertainty of this for the moment. Awaiting part to confirm.
NRC RS-TSN-RRS-008 | Yes | Holes to be created in the nozzle to secure the eye bolts using the nut.
NRC RS-TSN-RRS-007 | Yes | We have a role of shock cords to customize the size
NRC RS-TSN-RRS-008 | Yes | They’re kevlar.
NRC RS-MRD-MIS-001 | No | The OpenRocket simulation reached an apogee of just shy of 2200ft
NRC RS-MRD-MIS-002 | No | We don’t reach beyond the target height.
NRC RS-MRD-MIS-003 | Yes | Theoretically impossible based on simulations
NRC RS-MRD-MIS-004 | Yes | Motor fits in the guidelines
NRC RS-MRD-MIS-005 | Yes | It’s been purchased through UKSEDs
| NRC RS-MRD-MIS-006 | Yes | The motor form was submitted
| NRC RS-MRD-MIS-007 | Partially | To be tested
| NRC RS-MRD-MIS-008 | Partially | To be tested

# System Engineering

NRC RS-MRD-CPD-001 | Yes | 5V is being used
NRC RS-MRD-CPD-002 | Yes | The power of the battery supports the system for approximately 1 hour 30 minutes
NRC RS-MRD-CPD-003 | Yes | Current of 1.5 amps will power the Customers Payload.
NRC RS-MRD-CPD-004 | Yes | Position of port is bottom. Connectors and cables have arrived
NRC RS-MRD-CPD-005 | Yes | Provided by the launch service
NRC RS-MRD-CPD-006 | Yes | The adapter has been chosen and integrated into the Avionics Sled
NRC RS-MRD-CPD-007 | Yes | Payload bay has measurements are 45mm diameter and 53mm length.
NRC RS-MRD-CPD-008 | Yes | Design of rocket and integrated payload accounts for this
NRC RS-MRD-CPD-009 | Partially | Design confirmed. Finals holes will be drilled when avionics sled is printed


NRC RS-MRD-CPD-010 | Yes | Theres a hole in the rocket for the camera.
NRC RS-MRD-CPD-011 | Yes | Bolts have arrived
NRC RS-MRD-RPD-001 | Partially | Testing of single parts are complete. Awaiting PCB design verification
NRC RS-MRD-RPD-002 | Yes | Using the barometer on a 10dof IMU
NRC RS-MRD-RPD-003 | Partially | individual parts are working. Screen works
NRC RS-MRD-RPD-004 | Partially | individual parts are working.
| NRC RS-MRD-RPD-005 | Partially | To be printed
| NRC RS-MRD-RPD-006 | Yes | Multiple sensor included in the rocket. Still deciding shall be used for this part of the requirement.

# Testing

# All Components have been


# tested individually and have met the required parameters needed for a

safe and secure flight.

# Payload testing results


# Payload testing results


# Risks & Next Steps

# Risks :

1 - Motor Failure - Occasionally, a motor's casing can fail, leading to an explosion on the pad or in mid-air. This is why a minimum safety distance

# (usually 10-20 meters)

2 - Ballistic Re-entry - If the recovery system fails to deploy, the rocket will just freefall to the ground.
3 - Structural Failure – High-velocity flights exert massive G-forces. If the rocket fins aren't aligned or its airframe is weak, the rocket can "shred" or flutter, leading to an unpredictable flight path.
4 - Ignition Misfires - If the rocket doesn't launch after the countdown, the risk of a "hang-fire" (delayed ignition) is high
5 - Pyrotechnic Handling –during launch and manufacturing our teem will be working with black powder or flash paper for ejection charges and recovery systems . Improper handling can cause premature ignition, which can lead to burns or eye injuries
6 - Launch Pad Stability - High winds (usually above 15-20 mph) can tip a launch ,where the rocket veers into the wind and flies toward the spectators or away from the safe recovery zone.
7 - Hazardous Terrain - Rockets rarely land exactly where you want them. Recovery can lead you into high trees, water hazards, or near power

# lines

# Next steps : 1 – manufacture motor casing


# 2 – review and test ejection system 3 – put rocket together

# End Slide

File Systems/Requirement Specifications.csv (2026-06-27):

Requirement ID | Rev | Met? [Yes, No, Partially] | Rationale
NRC RS-TSN-MOR-001 | A | Yes | Mount designed to maximise strength and minimise weight; material has sufficient heat tolerance. Fits tightly to the top, secured with screws to the body, transferring thrust from the motor to the rocket. Rear clamps also fit tightly and are secured with screws to the body.
NRC RS-TSN-MOR-002 | A | Yes | Has been tested and can withstand the force
NRC RS-TSN-MOR-003 | A | Yes | Has been tested and can withstand the force
NRC RS-TSN-SMN-001 | A | Yes | See OpenRocket design
NRC RS-TSN-SMN-003 | A | Yes | See OpenRocket design
NRC RS-TSN-SAR-001 | A | Yes | Fins have been fixed in line with the longitudinal axis of the rocket
NRC RS-TSN-SAR-002 | A | Yes | Fin designs were tested to specification and found able to withstand high levels of strain
NRC RS-TSN-SAR-003 | A | Yes | See above
NRC RS-TSN-SAR-004 | A | Yes | Main body was tested with various weights in excess of 2 kg and found resilient to high lateral and longitudinal forces
NRC RS-TSN-SAR-005 | A | Yes | Nose cone's coupling with the main body is equal to 1 diameter of the main body
NRC RS-TSN-SAR-006 | A | Yes | All structural parts have been tested to specification and can withstand all expected loads
NRC RS-TSN-SAR-007 | A | Partially | Rail buttons have been ordered but have not yet arrived
NRC RS-TSN-SAR-008 | A | Yes | FEA analysis was not used for parts testing
NRC RS-TSN-ESS-001 | A | Yes | Main battery 2S 2200 mAh at ~60 mA (rideshare) plus customer payload at 1.5 A; total ~1.56 A draw. 2200 mAh at 7.8 W gives about 50 minutes runtime.
NRC RS-TSN-ESS-002 | A | Yes | Avionics sled can be removed by unscrewing six screws, allowing removal and arming in under 5 minutes
NRC RS-TSN-ESS-003 | A | Yes | No single-core wires have been used
NRC RS-TSN-ESS-004 | A | Yes | The team conforms to Ofcom's IR 2030 RF regulation as no radio has been used
NRC RS-TSN-RRS-001 | A | Yes | The vehicle has a recovery system
NRC RS-TSN-RRS-002 | A | Yes | The descent speed of the vehicle is less than 15 m/s
NRC RS-TSN-RRS-003 | A | Yes | The vehicle will not drift more than one kilometre
NRC RS-TSN-RRS-004 | A | Yes | The flight computer used is UKRA qualified
NRC RS-TSN-RRS-005 | A | Yes | The flight controller uses a separate battery and is therefore entirely isolated from the payload's battery
NRC RS-TSN-RRS-006 | A | Yes | Tilt switches have not been used
NRC RS-TSN-RRS-007 | A | Yes | The flight computer has an external disarming mechanism
NRC RS-TSN-RRS-008 | A | Yes | Eye bolts with screws have been used
NRC RS-TSN-RRS-007 | A | Yes | The shock cords are above the minimum length
NRC RS-TSN-RRS-008 | A | Yes | The shock cords are made of Kevlar
NRC RS-TSN-ARY-001 | A | Yes | Recovery conforms to CAA UAS law
NRC RS-TSN-ARY-002 | A | Yes | Recovery conforms to UKRA safety code
NRC RS-TSN-ARY-003 | A | Yes | We are not using active stabilisation
NRC RS-MRD-MIS-001 | A | Yes | The motor chosen and the design of the rocket theoretically should reach this apogee
NRC RS-MRD-MIS-002 | A | Yes | Dual-deployment is not being used
NRC RS-MRD-MIS-003 | A | Yes | Rocket will be unable to reach this height
NRC RS-MRD-MIS-004 | A | Yes | Motor was picked from the provided list that complied with these guidelines
NRC RS-MRD-MIS-005 | A | Yes | To be supplied by UKSEDS on the day
NRC RS-MRD-MIS-006 | A | Yes | Confirmation email has been received
NRC RS-MRD-MIS-007 | A | Yes | The RPD weighs 102 g
NRC RS-MRD-MIS-008 | A | Yes | The rocket will not reach further than 750 m
NRC RS-MRD-CPD-001 | B | Yes | A 5 V 4 A buck converter with an XT30 connector is used to power the CPD
NRC RS-MRD-CPD-002 | A | Yes | See NRC RS-TSN-ESS-001 (Rev A)
NRC RS-MRD-CPD-003 | A | Yes | 18650CA-2S-3J battery has a max discharge current of 2.2 A; CPD current draw is 7.5 W / 5 V = 1.5 A
NRC RS-MRD-CPD-004 | B | Yes | The buck converter used for powering the CPD has an XT30 connector
NRC RS-MRD-CPD-005 | A | Yes | AstraNova provides an SD card for the CPD
NRC RS-MRD-CPD-006 | B | Yes | The avionics sled has a launch vehicle adapter mounted at the top for the CPD
NRC RS-MRD-CPD-007 | B | Yes | As per the model, the avionics sled has a diameter of 50 mm and clearance of over 53 mm
NRC RS-MRD-CPD-008 | B | Yes | As per the 3D assembly, the customer payload is mounted concentrically
NRC RS-MRD-CPD-009 | B | Yes | Holes have been drilled into the side of the rocket for external access
NRC RS-MRD-CPD-010 | A | Yes | The entire avionics sled is unpressurised
NRC RS-MRD-CPD-011 | A | Yes | AstraNova has M3 bolts for mounting the CPD
NRC RS-MRD-RPD-001 | A | Yes | Custom PCB designed in Fusion 360, manufactured and populated in-house
NRC RS-MRD-RPD-002 | A | Yes | BMP280 barometer, bench tested; altitude reading verified by walking up and down a flight of stairs
NRC RS-MRD-RPD-003 | A | Yes | Python script generates a plot from SD card data; demonstrated in bench test video
NRC RS-MRD-RPD-004 | A | Yes | Code calculates and logs the apogee value to the SD card and e-paper display
NRC RS-MRD-RPD-005 | A | Yes | Silkscreen is on the rideshare PCB (example photo in following slides)
NRC RS-MRD-RPD-006 | A | Yes | 10-DOF IMU logs acceleration, gyro, and mag data throughout flight

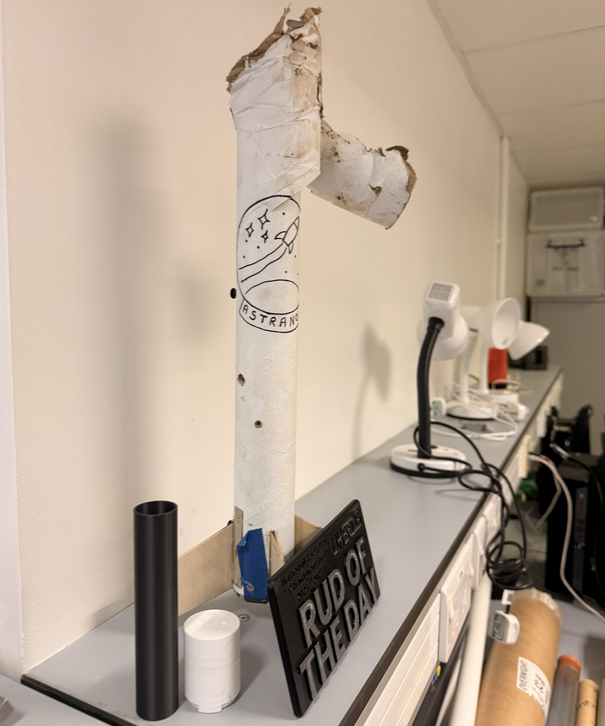
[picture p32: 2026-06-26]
Figures/rocket_aftermath_lab.jpg

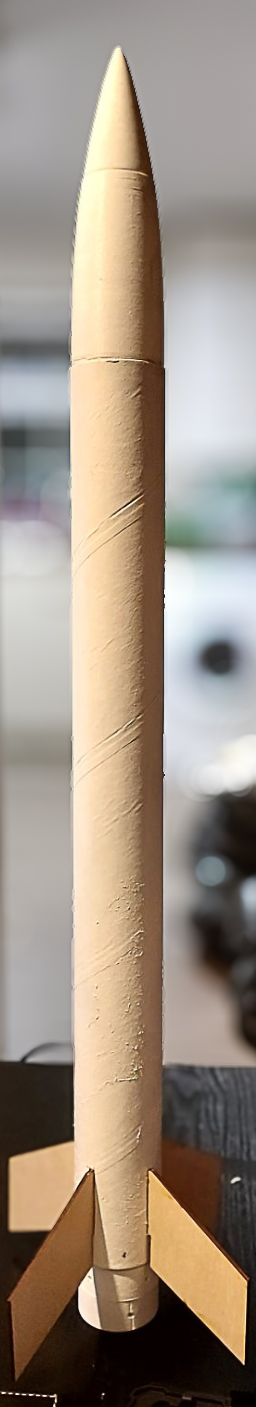
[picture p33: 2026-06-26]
Figures/structures.jpg

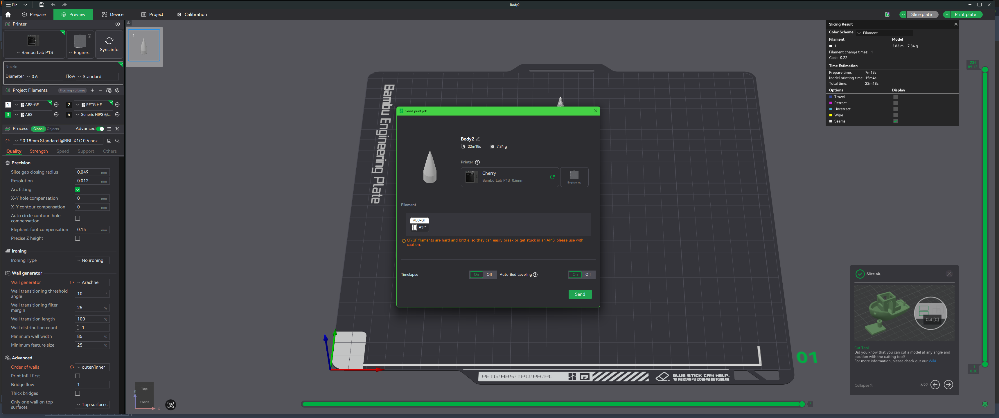
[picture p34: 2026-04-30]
Recovery/Screenshot 2026-04-30 122706.png

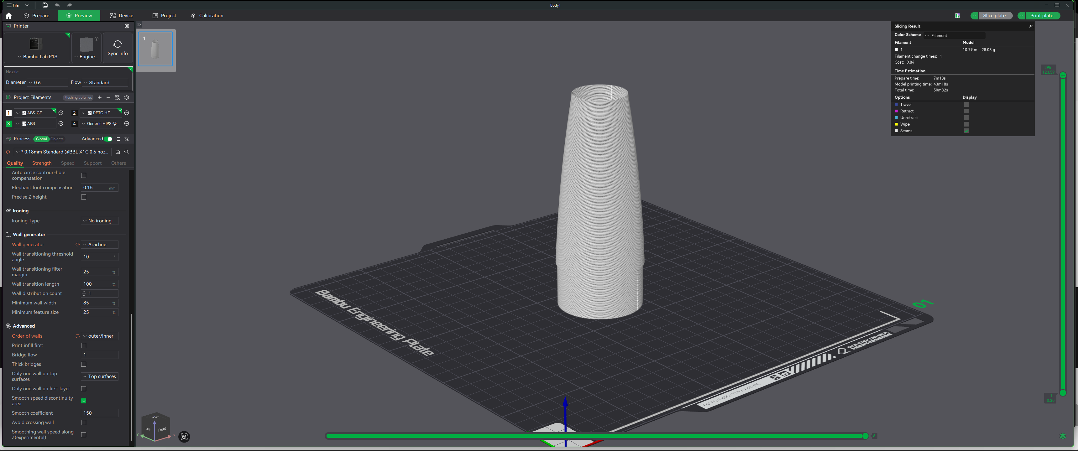
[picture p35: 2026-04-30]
Recovery/Screenshot 2026-04-30 114004.png

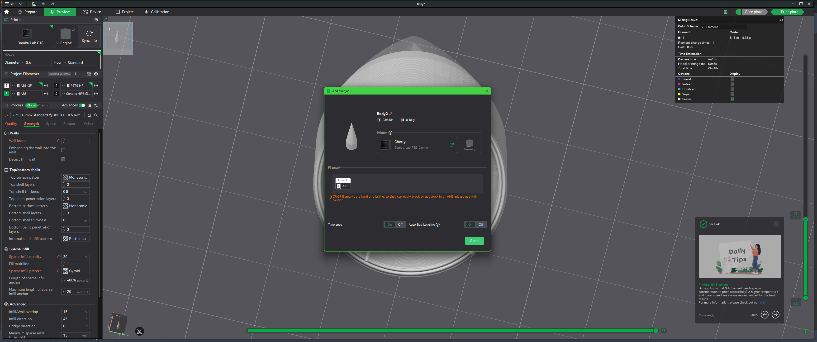
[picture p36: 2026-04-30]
Recovery/Screenshot 2026-04-30 110050.png

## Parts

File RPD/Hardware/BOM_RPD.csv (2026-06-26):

Item | Component | Description | Manufacturer Part No | Supplier Part No | Supplier | Qty | Unit Price (GBP) | Line Total (GBP)
1 | Buzzer | Board-mount buzzer, 8.5 mm, 5 V, 100 dB, SMT | CMT-8504-100-SMT-TR | 490-CMT-8504100SMTTR | Mouser | 1 | 1.18 | 1.18
2 | microSD connector | microSD push-pull connector, SMT, 1.42 mm height | 104031-0811 | 538-104031-0811 | Mouser | 1 | 1.62 | 1.62
3 | LED, green | Green LED, clear tinted, 10-15 mcd @ 10 mA | TLHG4201 | 78-TLHG4201 | Mouser | 1 | 0.863 | 0.86
4 | LED, red | Red LED, diffused | TLLR4401 | 78-TLLR4401 | Mouser | 1 | 0.375 | 0.38
5 | LDO regulator, 3.3 V | LDO voltage regulator, 3.3 V 0.8 A | LD1117S33TR | 511-LD1117S33 | Mouser | 1 | 0.255 | 0.26
6 | LDO regulator, 5.0 V | LDO voltage regulator, 5.0 V 0.8 A | LD1117S50TR | 511-LD1117S50 | Mouser | 1 | 0.292 | 0.29
7 | Level shifter | Hex non-inverting buffer / level shifter, CMOS | CD74HC4050NSR | 595-CD74HC4050NSR | Mouser | 1 | 0.496 | 0.5
8 | Tactile switch | Tactile switch, 6 x 6 mm, 260 gf, SPST, IP67 | TS05-66-50-BK-260-SMT-67 | 179-TS056650260SMT67 | Mouser | 2 | 0.263 | 0.53
9 | Raspberry Pi Pico 2 | Raspberry Pi Pico 2, RP2350, 4 MB flash | SC1631 | 358-SC1631 | Mouser | 1 | 3.75 | 3.75
10 | Resistor, 1 kohm | Thick-film resistor, 1 kohm, 1206, 0.5% | ESR18EZPD1001 | 755-ESR18EZPD1001 | Mouser | 1 | 0.115 | 0.12
11 | Resistor, 10 kohm | Thick-film resistor, 10 kohm, 3216, 5% | SFR18EZPJ103 | 755-SFR18EZPJ103 | Mouser | 5 | 0.072 | 0.36
12 | LED, red (0805) | Red SMD LED, 0805 | Q62702P5178 | 720-Q62702P5178 | Mouser | 1 | 0.111 | 0.11
13 | Resistor, 270 ohm | Thick-film resistor, 270 ohm, 1210, 1%, 2.5 W | CRCW1210270RFKEAHP | 71-CRCW1210270RFKEAH | Mouser | 2 | 0.377 | 0.75
14 | Resistor, 680 ohm | Thick-film resistor, 680 ohm, 1210, 1%, 2.5 W | CRCW1210680RFKEAHP | 71-CRCW1210680RFKEAH | Mouser | 1 | 0.18 | 0.18
15 | IMU, 10-DOF | Waveshare 10-DOF IMU Sensor (D); ICM-20948 + BMP280 |  | SKU:15965 | Waveshare | 1 | 25.39 | 25.39
16 | e-Paper display, 2.9" | Waveshare 2.9 inch e-Ink display module, 296 x 128 |  | SKU:12956 | Waveshare | 1 | 21.99 | 21.99
17 | MOSFET | MOSFET, IRLML2502, 20 V 4.2 A | IRLML2502TRPBF |  |  | 1 | 1.2 | 1.2
18 | Capacitor, 10 uF | MLCC, 10 uF, 35 V, 1206, X7R | C3216X7R1V106K160AC |  |  | 2 | 0.19 | 0.38
19 | Capacitor, 0.1 uF | MLCC, 0.1 uF, 50 V, 1206, X7R | C1206C104K5RAC7210 |  |  | 2 | 0.03 | 0.06
20 | Diode, Schottky | Schottky diode, 1N5819W, SMD | 1N5819W |  |  | 1 | 0.33 | 0.33
21 | Buck converter | Waveshare DC5-36 V to 3.3 V buck converter | DC5-36-TO-DC3V3-5 |  | Waveshare | 1 | 3.47 | 3.47
22 | IC header, 20-way | IC header, 20 way | D01-9922046 | D01-9922046 | CPC | 1 | 3.16 | 3.16
Total (ex. shipping and VAT) |  |  |  |  |  | 30 |  | 66.86

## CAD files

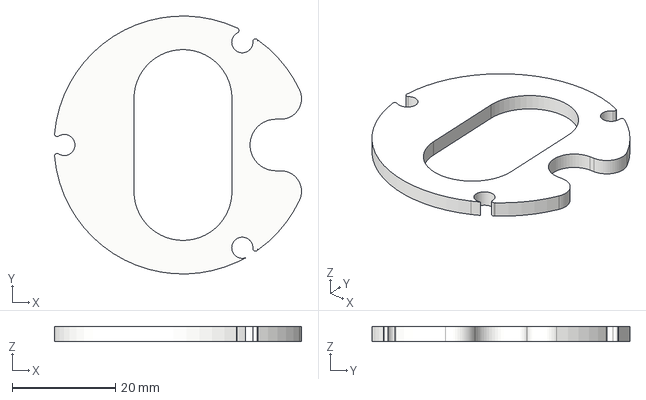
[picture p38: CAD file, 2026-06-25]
Avionics/avionics_battery_holder.step
47.9 x 50.0 x 3.00 mm

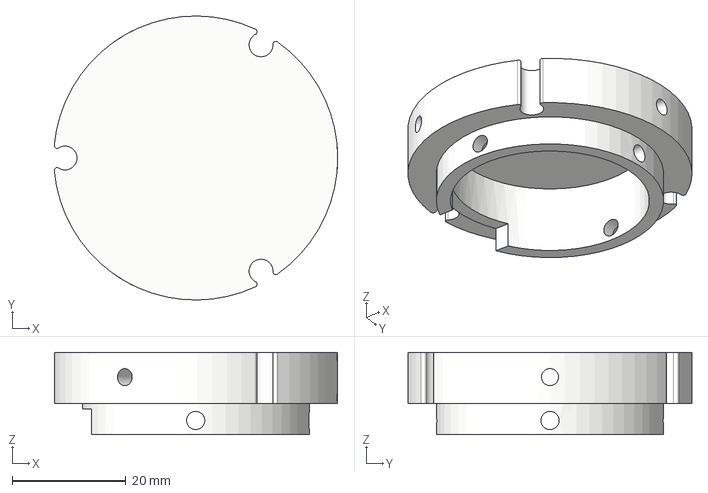
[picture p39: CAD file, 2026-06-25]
CPD/cpd_vehicle_launch adapter.step
49.9 x 50.0 x 14.5 mm

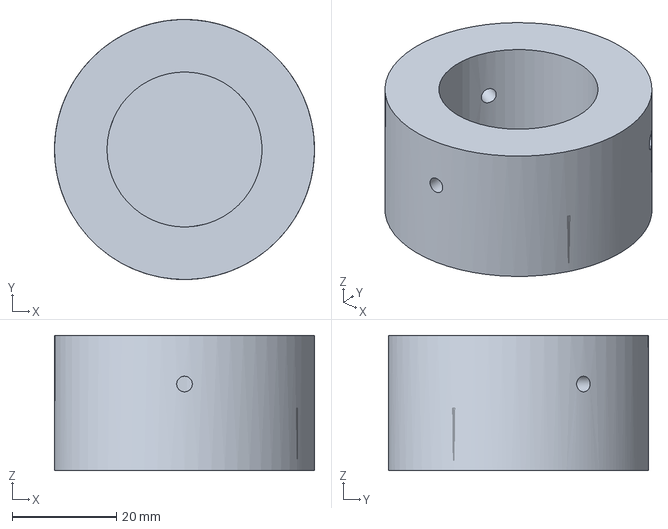
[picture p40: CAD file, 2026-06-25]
Propulsion/Final_motor_casing_mount_top.step
50.0 x 50.0 x 26.0 mm

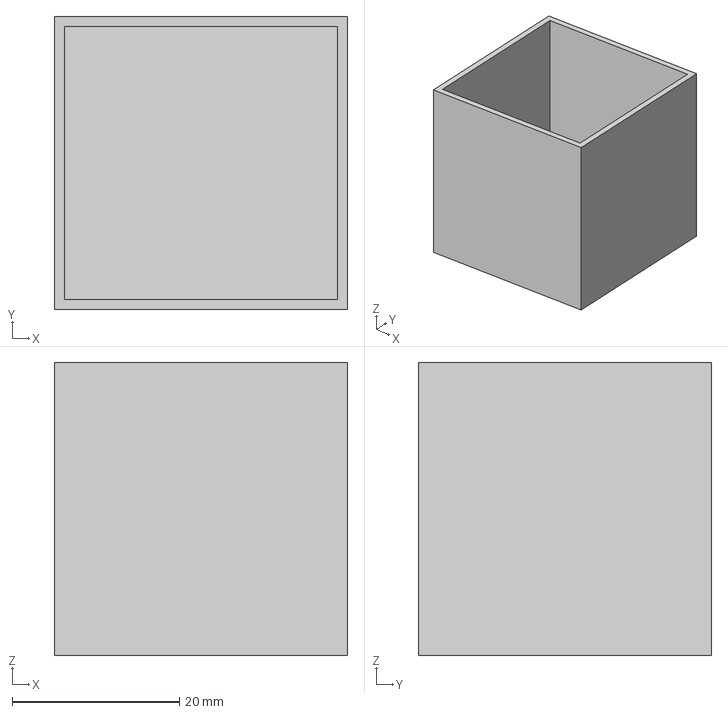
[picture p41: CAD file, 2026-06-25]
Recovery/flashpaper_chamber_inner_v1.step
35.0 x 35.0 x 35.0 mm

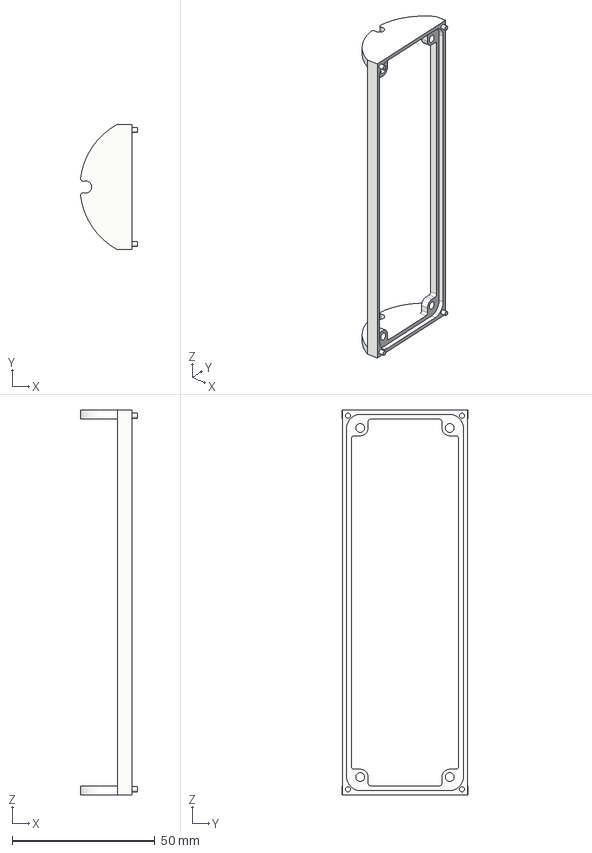
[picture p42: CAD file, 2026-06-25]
RPD/Hardware/source/rpd_casing_rear.step
20.0 x 44.0 x 135.0 mm

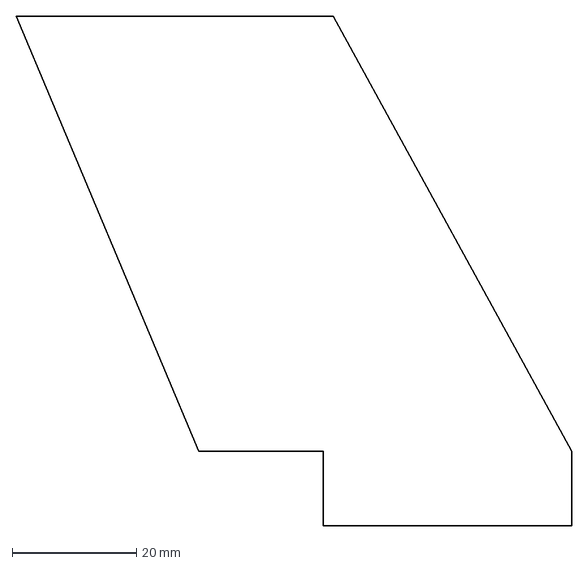
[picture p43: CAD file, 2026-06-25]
Structures/Final_fins.dxf
89.5 x 82.0 mm

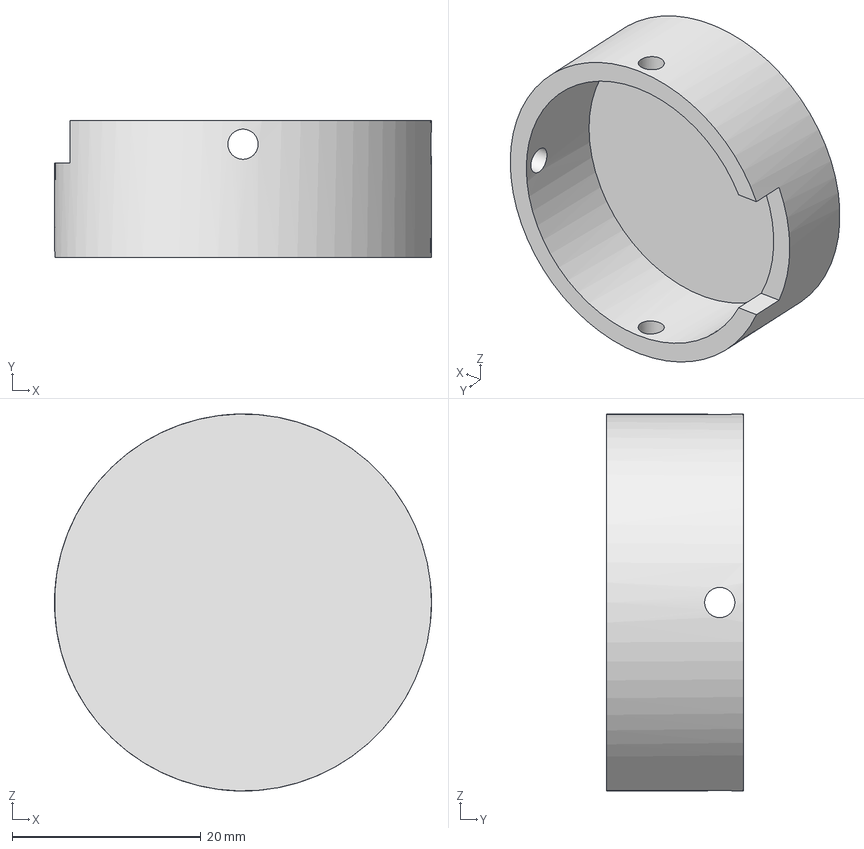
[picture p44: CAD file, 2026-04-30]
CPD/LVA_no_XT30_V1.stp
40.0 x 14.5 x 40.0 mm

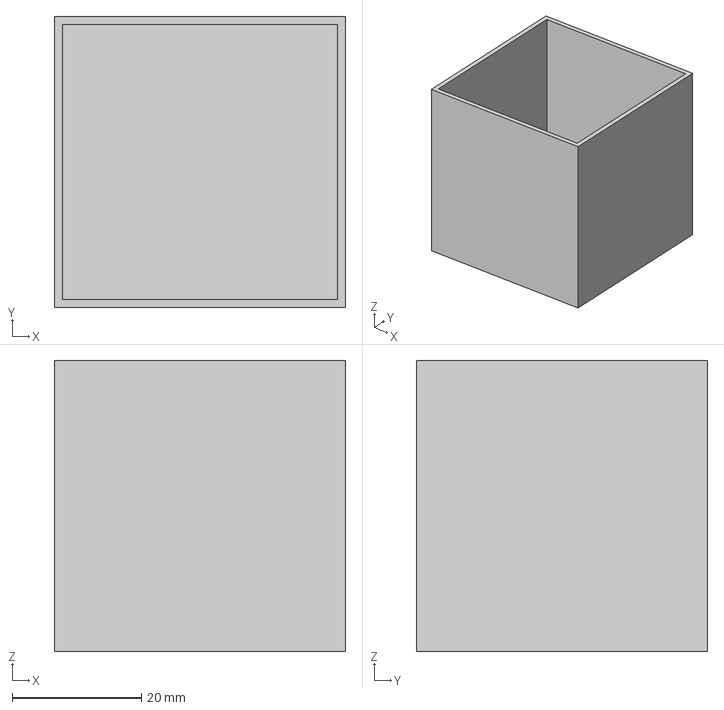
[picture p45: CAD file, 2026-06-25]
Recovery/flashpaper_chamber_outer_v1.step
45.0 x 45.0 x 45.0 mm

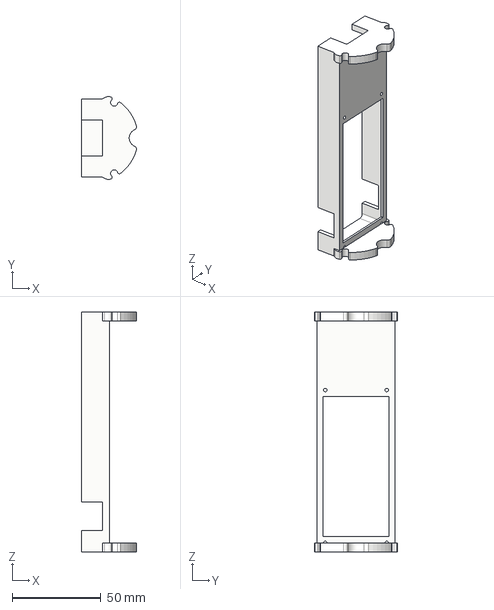
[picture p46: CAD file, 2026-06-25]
RPD/Hardware/source/rpd_casing_front.step
30.9 x 46.6 x 135.0 mm

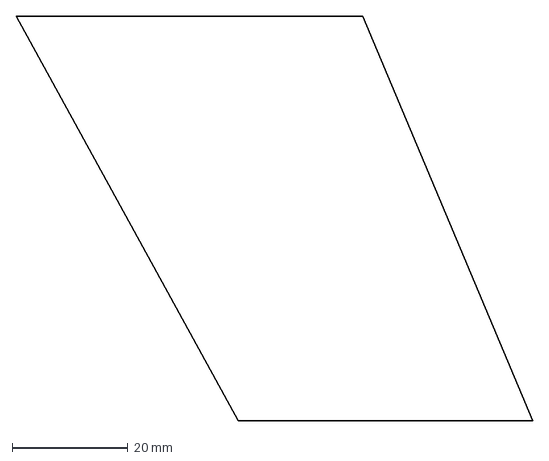
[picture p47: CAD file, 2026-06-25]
Structures/fins_v1.dxf
89.2 x 69.8 mm

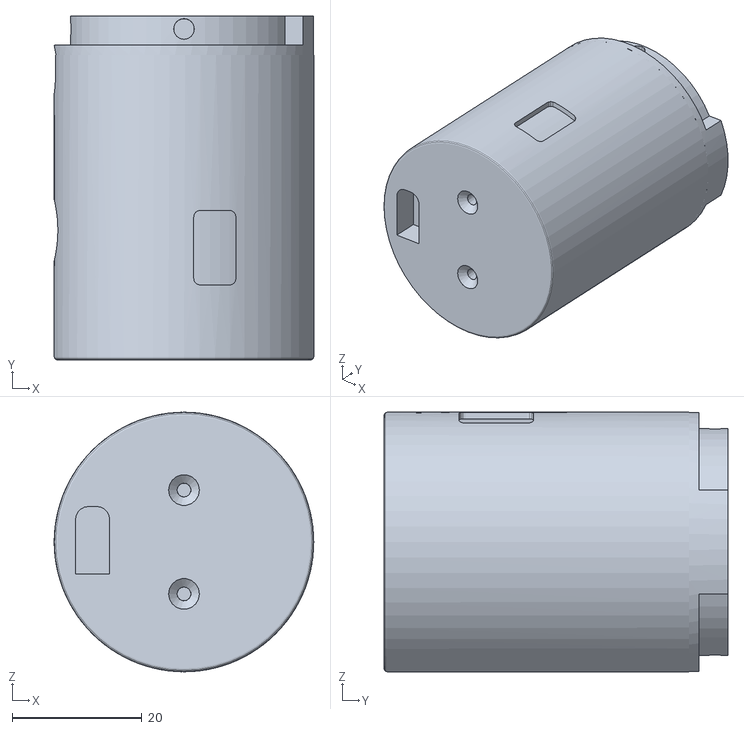
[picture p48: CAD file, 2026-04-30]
CPD/Customer Payload Dummy.stl
40.0 x 53.0 x 40.0

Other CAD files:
CPD/LVA_XT30_V1.stp
CPD/LVA_XT30_V1.ipt
CPD/LVA_XT30_V1.stl
CPD/LVA_no_XT30_V1.ipt
CPD/LVA_no_XT30_V1.stl
Propulsion/Final_rocket_mount_1.f3d
Propulsion/Final_rocket_mount_2.f3d
Propulsion/rocket_mount_top_v1.f3d
Propulsion/roket_mount_bottom_v1.f3d
Propulsion/roket_mount_top_v2.f3d
Recovery/Final_flashpaper_chamber_inner.f3d
Recovery/Final_flashpaper_chamber_outer.f3d
Recovery/NOSECONE 2 v2.f3d
Recovery/NOSECONE V3 v2.f3d
Recovery/NOSECONE V3.f3d
Recovery/nose cone v2.f3d
Recovery/noseconetop v3.f3d

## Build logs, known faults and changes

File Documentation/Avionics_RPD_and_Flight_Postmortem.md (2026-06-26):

# RPD Avionics: Design and Flight Post-Mortem

A full write-up of the **Rocket Position Data recorder (RPD)**, the flight data logger flown by UKC AstraNova at the UKSEDS National Rocketry Championship 2025-26. This document covers the hardware, the firmware, and a complete root-cause analysis of why the board returned no flight data, with the design changes that follow from it.

> **Scope:** this is the avionics subsystem only. The vehicle-level recovery failure is summarised where it matters for context, but the RPD is the focus.

## Summary

The RPD is a self-contained logger on a 2-layer PCB; a **Raspberry Pi Pico 2 (RP2350)** reads a **Waveshare 10-DOF IMU (ICM-20948 + BMP280)** and a **DHT22**, writes a timestamped CSV to micro-SD through the flight, and reports peak altitude on a **2.9" e-paper** screen after landing. The firmware is an autonomous flight state machine driven by barometric altitude and acceleration, with detection thresholds tuned from the team's OpenRocket model. The board is electrically efficient (around **60 mA**) and mechanically robust (it survived a ballistic impact intact). It failed to record on the day for a single reason: a **shared-source power brownout** that the board had no transient margin to absorb. Every observed symptom (screen never refreshed, arm never completed, only a startup row on the card, zero button still working) falls out of that one cause.

## Hardware

| Subsystem | Part | Bus |
| --- | --- | --- |
| MCU | Raspberry Pi Pico 2 (RP2350) | ; |
| IMU + barometer | Waveshare 10-DOF (ICM-20948 + BMP280) | I2C (Wire1, GP26/27) |
| Storage | micro-SD card | SPI0 |
| Display | 2.9" e-paper V2 | SPI1 |
| Environment | DHT22 | 1-wire (GP8) |
| Indicators | buzzer (GP7), status LED (GP28), ARM / ZERO buttons (GP0 / GP1) | GPIO |
| Power in | 2S LiPo via keyed XT30 | ; |

The board was designed in **Fusion 360 (Eagle)**, hand-routed for the critical nets (paired I2C, SPI to SD and e-paper, 0.5 to 1 mm power traces), given a bottom-layer ground plane, fabbed at **JLCPCB** as a 2-layer board, and SMD-assembled with engineering lab-tech support. Two revisions were produced: **Rev V2** in ENIG on black soldermask as the flight board (including a CD74HC4050 level-shifter path), and **Rev B** in HASL as a test article with the level shifter removed (redundant for all-3.3 V logic) and the SD card wired directly.

### Power architecture

```
2S LiPo --+-- LD1117S50 (5V) -- LD1117S33 (3.3V) -- RPD rail  (Pico, sensors, SD, e-paper)
          |
          +-- buck converter ----------------------- customer payload (CPD)
```

Two design choices in this diagram became load-bearing in the post-mortem. First, the RPD rail is produced by a **cascade** of high-dropout LD1117 regulators (5 V then 3.3 V) rather than a single regulator off the pack. Second, the RPD and the customer payload share **only the battery input terminal**; there is no shared regulated rail, so the only path for one to disturb the other is by pulling the battery terminal down through the pack and wiring resistance.

## Firmware

Arduino-framework C++ on the RP2350. The main loop runs a non-blocking flight state machine and, once armed, logs continuously to SD.

```mermaid
stateDiagram-v2
    [*] --> IDLE
    IDLE --> ARMED: ARM button (set baseline, open log)
    ARMED --> ASCENT: accel > 3 g (debounced 150 ms)
    ASCENT --> DESCENT: altitude falling 500 ms (apogee)
    DESCENT --> LANDED: AGL < 330 ft AND 10 ft stable band AND ~1 g, held 5 s
    ASCENT --> LANDED: 180 s failsafe
    DESCENT --> LANDED: 180 s failsafe
    LANDED --> IDLE: ARM button (reset)
```

### Detection logic

| Parameter | Value | Reason |
| --- | --- | --- |
| Launch threshold | 3 g, 150 ms debounce | clear of pad noise, well under boost peak |
| Accel full-scale | +/-16 g | boost peaks around 11 g; lower FSR clips the data |
| Apogee | barometric, 500 ms of falling altitude | orientation-independent; immune to weathercocking |
| Landing (primary) | AGL flat within a 10 ft band | canopy descent also reads about 1 g, so altitude is the trustworthy signal |
| Landing gate | only below 330 ft AGL | rejects false triggers during descent |
| Landing confirm | 5 s | avoids a momentary stall reading as landed |
| Time failsafe | 180 s | last-resort stop at about 2x real flight time |

These constants were set from the OpenRocket simulation (parsed from the `.ork` file, which is a zip archive containing XML): apogee around **2020 ft at about 11.2 s**, peak acceleration around **11.2 g**, total flight around **83 s**, descent around **8.5 m/s**. The 180 s failsafe sits at roughly twice the real flight duration; the 330 ft gate sits well below apogee.

### Log format

CSV to `flightlog.csv`, flushed every second, with a `STARTUP` calibration row at power-on and `LOG` rows once armed:

```
TimeMs,AccelX,AccelY,AccelZ,GyroX,GyroY,GyroZ,DHTTempC,DHTHum,IMUTempC,AltitudeM,Event
```

## The flight

The boost was clean and vertical, which is worth stating plainly because it validated the aerodynamic and stability design directly; the stability margin held in the intended 1.75 to 2.5 calibre band and the vehicle tracked straight off the rail. That same straightness then set up the recovery failure at apogee. The RPD powered on at the pad, beeped, and wrote its `STARTUP` row to the card. It did not record the flight.

### What went well

- **Stable, straight ascent**, validating the aerodynamics and the stability margin.
- **ABS-GF thermal margin.** The printed parts were made in glass-filled ABS for its rigidity and heat resistance, since there was concern the motor casing might melt nearby plastic. In flight the heat caused no issue at all and the parts came through untouched, so the material choice was vindicated.
- **Flew on a substitute motor** (see below), which speaks to margin in the design.

### Motor substitution

The motor the team had ordered through UKSEDS was taken before launch, so AstraNova was issued a different motor that the flight had not been calculated or simulated for. The rocket flew regardless, but the substitution changed the expected flight profile from what the OpenRocket model had been tuned against, so the as-flown trajectory should be read with that in mind.

### Recovery failure (vehicle level)

Recovery was a nose-cone separation event: a flash-paper ejection charge fired by an igniter, commanded by a separate Mercury V1 flight computer on its own isolated battery, deploying a 24" Spherachute. Deployment depended on the flight computer detecting a near-freefall, under 1 g condition at apogee. Because the rocket flew so straight on the way up, it carried that momentum over the top and pitched sideways rather than nosing into a clean vertical descent; it never "went straight down." Broadside, aerodynamic load kept the measured acceleration above 1 g, so the deployment window never opened and the rocket came in ballistic; the nose and carbon rods were destroyed on impact.

The lesson is direct: a single accelerometer threshold is an unreliable apogee and deploy trigger, precisely because a stable, non-vertical attitude at apogee never produces the expected freefall reading. This is the same ambiguity the RPD avoids by detecting apogee barometrically; a pressure-based apogee signal does not care which way the airframe points, and a positive-to-negative crossing of vertical velocity would have fired regardless of attitude.

### RPD failure (avionics)

Symptoms recovered after the flight: the e-paper never refreshed (even at power-on); the ARM button never completed its action when the customer payload was connected in parallel, yet worked perfectly with the payload unplugged; the ZERO button always worked; the card held only the `STARTUP` row.

The decisive clue was that **arm failed only when the customer payload was connected**. A static fault (a bad button, a missing pull-down, a software bug on one path) would fail with or without the payload; a fault that appears only under the parallel load is a **power** fault. That reframes everything around the shared battery terminal.

The chain:

1. The pack itself is close to its limit. The 18650CA-2S-3J 2S 2200 mAh battery is rated to about 2.2 A maximum discharge, and the steady draw already sat near 1.56 A (about 1.5 A for the customer payload plus roughly 60 mA for the rideshare), leaving under 0.7 A of headroom before the pack's own rating.
2. The customer payload's buck converter loads the pack through the common battery terminal, so any sag it causes is shared with the RPD before the RPD draws anything of its own.
3. The cascaded **LD1117** regulators are high-dropout parts; they need over a volt of headroom to stay in regulation, so the cascade raises the brownout knee and spends most of the sag budget a single regulator would have kept.
4. There is **no bulk capacitance** on the board beyond the regulators' own stability caps, so every current burst has to be supplied in real time by a slow linear regulator on an already-loaded source; the board has no transient ride-through.

Now the events line up exactly:

- **Boot SD write survives.** The `STARTUP` row is written early in setup, before `epd.Init()` powers the e-paper; the rail is only feeding the MCU and IMU, so the SD inrush survives even with the payload connected.
- **E-paper never refreshes.** The e-paper is bistable (near-zero hold current) but its refresh fires an onboard charge pump that demands a brief current burst; on the loaded, sagging rail that burst cannot be supplied, so the panel never completes a refresh from power-on onward.
- **Arm never completes.** The arm handler opens the SD file and writes the header; that write transient, arriving when the display is already powered and the payload is loading, drops the 3.3 V rail below the RP2350 brownout threshold and resets the MCU mid-handler. The startup beep is non-blocking (a background timer), so a reset a millisecond into it cuts the tone to an inaudible click; to the operator the button simply did nothing.
- **Zero still works.** The ZERO handler touches neither the SD card nor a display refresh, so it draws no heavy transient and completes on the same sagging rail every time.
- **Payload unplugged, arm works.** Remove the payload and the pack terminal is no longer pre-loaded; the rail keeps enough headroom for the SD transient, and the full arm sequence (including the complete beep) runs.

One cause, every symptom. The SD card did not fail to write; the processor browned out underneath it. The card itself is almost certainly fine.

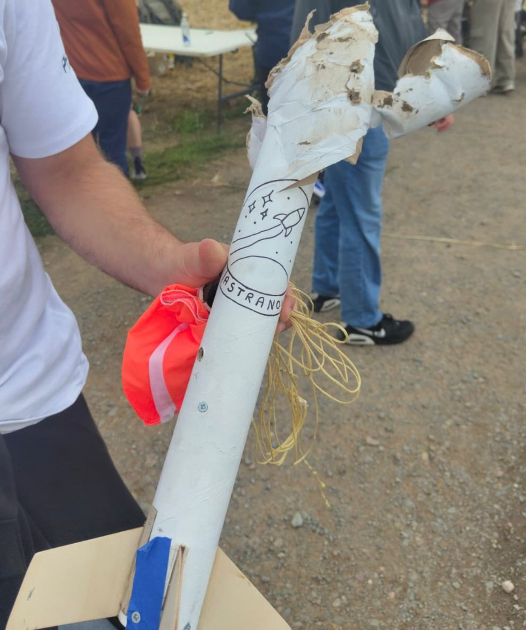
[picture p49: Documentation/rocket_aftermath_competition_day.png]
Rocket postmortem


## Fixes

In order of effect:

1. **Independent battery for the RPD.** Decoupling the recorder from the customer rail removes the shared-source coupling entirely and is the single change that breaks the whole chain. This was the intended design before a shared rail was adopted under time pressure.
2. **Drop the regulator cascade.** A single 3.3 V regulator straight off the pack buys back the sag budget the LD1117 cascade gave away, tolerating the pack drooping much further before brownout.
3. **Add bulk decoupling.** Bulk capacitance at the board input and next to the SD card and e-paper gives the rail the transient reservoir it never had, so an SD or charge-pump burst leans on the caps instead of the regulator.
4. **Firmware hardening.** Set the armed flag and begin logging before any display call, so a display problem can never gate logging; and put a timeout on every e-paper busy-wait (the stock driver waits on the BUSY pin with no timeout, which can hang the loop if the panel is unresponsive). On the RP2350 the display can run on the second core so it physically cannot stall logging.

Any one of the first two probably saves the flight; all four together make the rail robust.

## Lessons

- **Shared power rails with independent loads are a systems-integration hazard.** The fault appears only when the subsystems meet, which is the moment it is hardest to catch.
- **A flight recorder must never be blockable by its own display.** Blocking driver waits need timeouts, and logging must not sit behind a display call.
- **Decoupling is a design input, not an afterthought.** A board driving an SD card and an e-paper needs transient capacitance designed in from the start.
- **High-dropout regulator cascades waste headroom.** Each cascaded stage moves the brownout knee up; prefer a single regulator off the pack where possible.
- **Startup behaviour is a strong diagnostic.** Knowing the SD write happened but the screen never refreshed, and that arm failed only under the parallel load, narrowed the cause to power almost immediately.

The board was sound and the firmware logic was sound; the failure lived in the interaction between two subsystems and an under-decoupled shared supply. That is the most useful kind of failure to have once, early, on a student project rather than later on something that matters more.

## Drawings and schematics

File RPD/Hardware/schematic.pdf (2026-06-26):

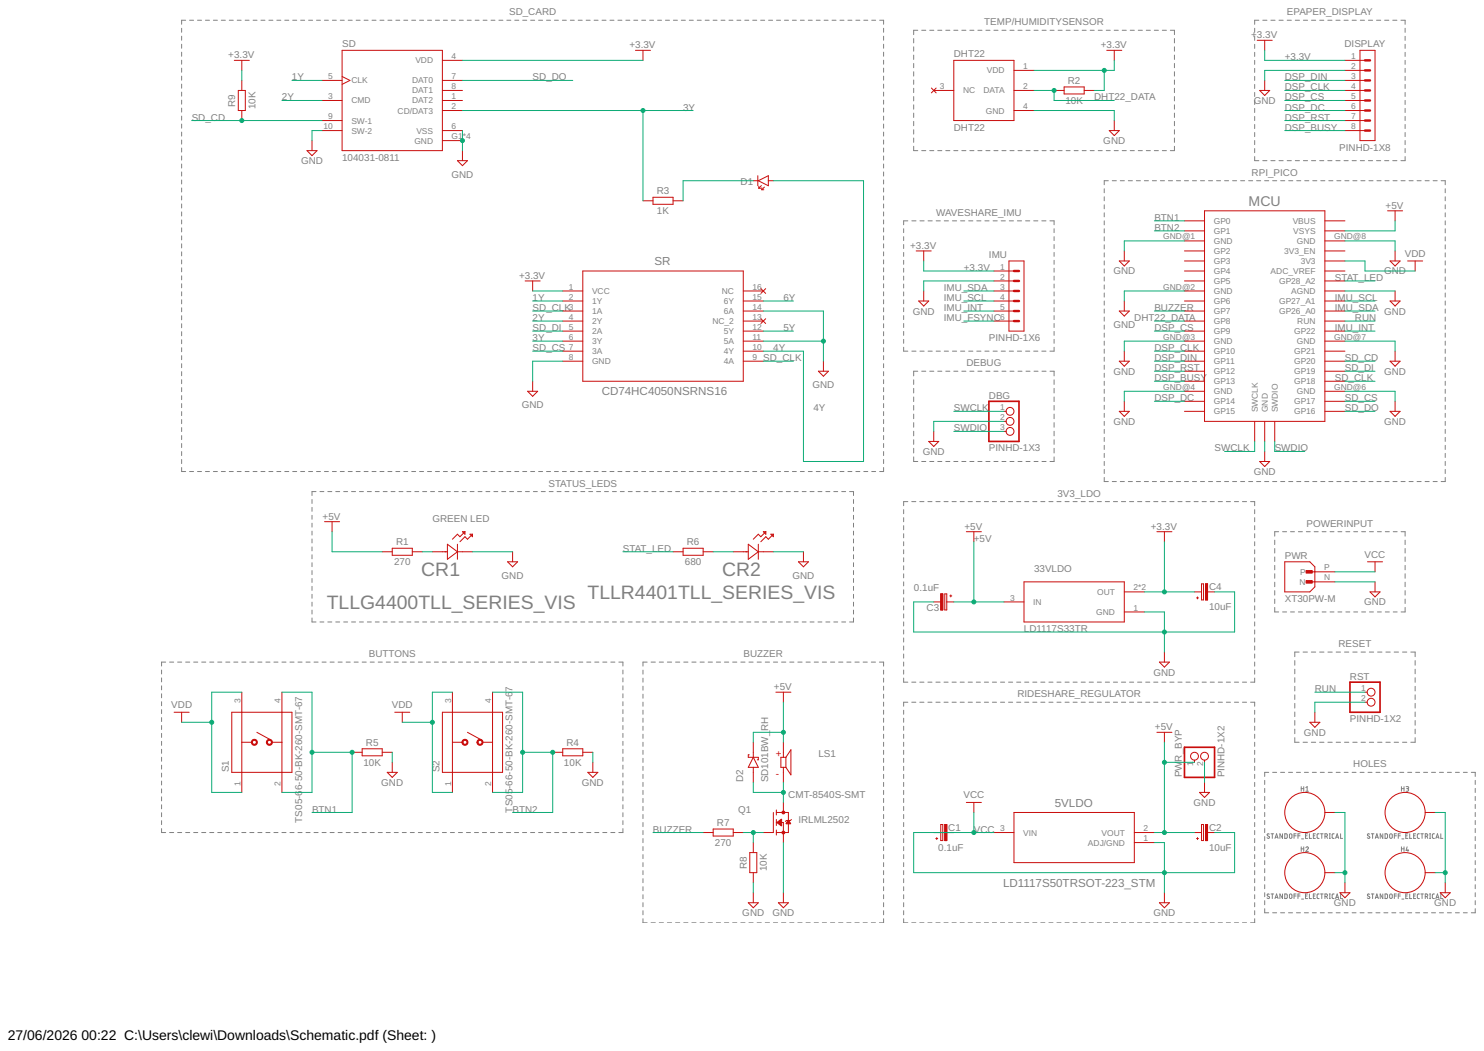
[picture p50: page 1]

27/06/2026 00:22 C:\Users\clewi\Downloads\Schematic.pdf (Sheet: )

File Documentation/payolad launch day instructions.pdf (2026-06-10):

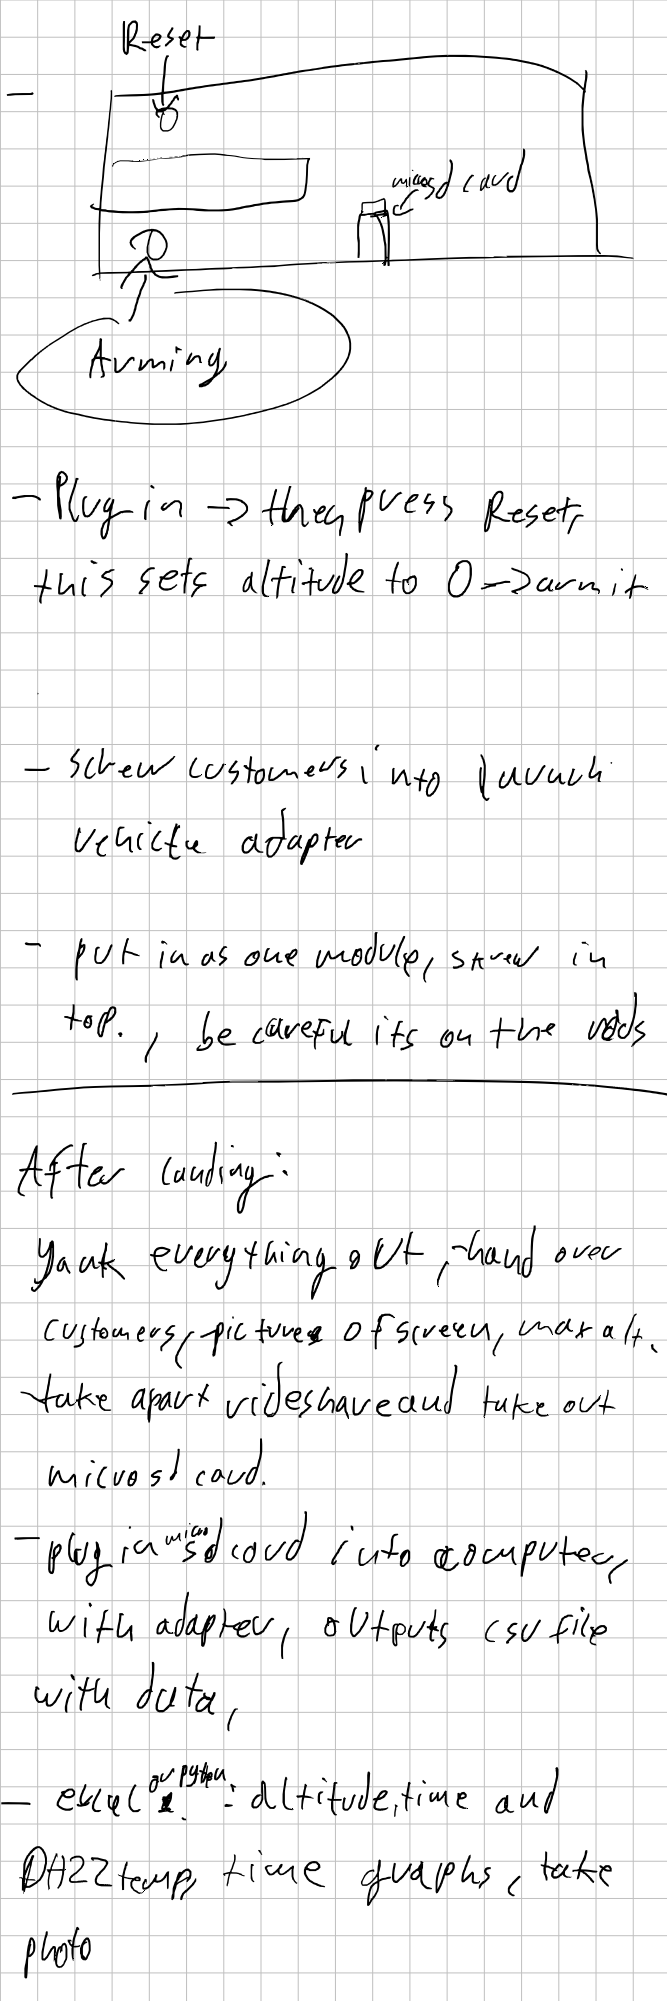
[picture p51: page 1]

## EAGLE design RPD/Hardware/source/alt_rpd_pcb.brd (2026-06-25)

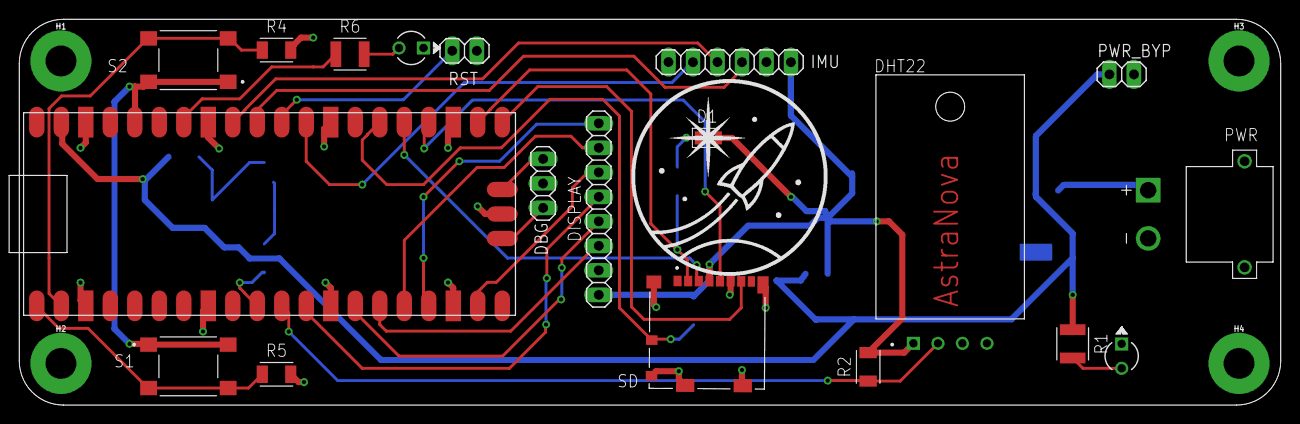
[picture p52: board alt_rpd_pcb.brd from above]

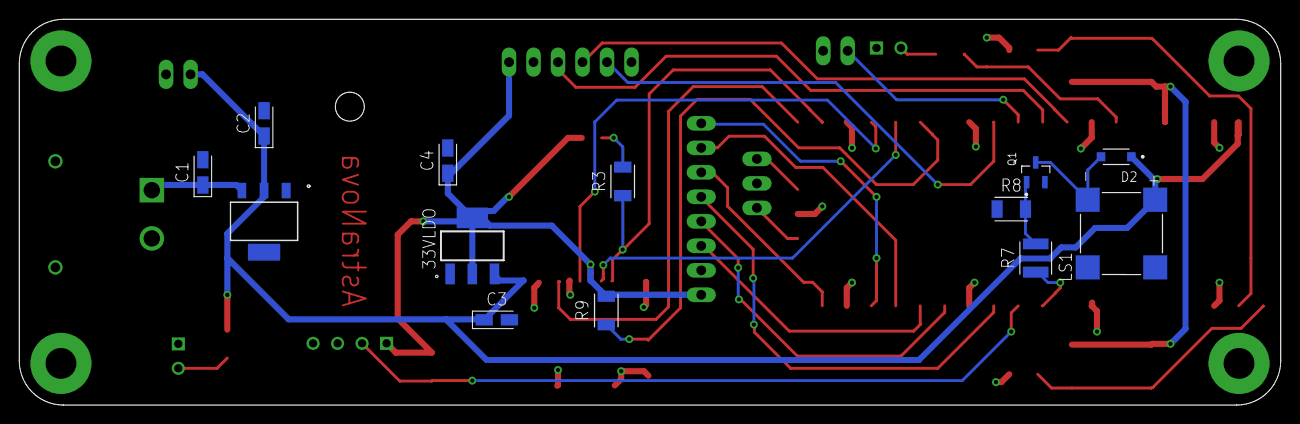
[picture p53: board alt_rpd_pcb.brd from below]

Board: 2 copper layers, 130.8 x 40.0 mm, 36 parts (13 on the bottom side), 32 nets.

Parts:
5VLDO: LD1117S50TRSOT-223_STM; SOT-223_STM
33VLDO: LD1117S33TR; SOT230P700X180-4N
C1, C3: 0.1uF; CAPMP3216X180N
C2, C4: 10uF; CAPMP3216X180N
CR1: TLLG4400TLL_SERIES_VIS; TLL_SERIES_VIS
CR2: TLLR4401TLL_SERIES_VIS; TLL_SERIES_VIS
D1: LED_RED; LEDC2012X110N_FLAT-R
D2: SD101BW_RH; DIO_SD101BW_RH
DBG: PINHD-1X3; 1X03
DHT22: DHT22; XDCR_DHT22
DISPLAY: PINHD-1X8; 1X08
H1, H2, H3, H4: STANDOFF_ELECTRICAL; STANDOFF-ELECTRICAL
IMU: PINHD-1X6; 1X06
LS1: CMT-8540S-SMT; CUI_CMT-8540S-SMT
MCU: RPI_PICO
PWR: XT30PW-M; AMASS_XT30PW-M
PWR_BYP: PINHD-1X2; 1X02
Q1: IRLML2502; SOT95P237X112-3N
R1, R7: 270; RESC3224X71
R2, R4, R5, R8, R9: 10K; RESC3216X70
R3: 1K; RESC3216X70
R6: 680; RESC3224X71
RST: PINHD-1X2; 1X02
S1, S2: TS05-66-50-BK-260-SMT-67; SW_TS05-66-50-BK-260-SMT-67
SD: 104031-0811; MOLEX_104031-0811

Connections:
+3.3V: 33VLDO.2, 33VLDO.4, C4.1, D1.A, DHT22.1, DISPLAY.1, IMU.1, R2.2, R9.2, SD.4
+5V: 5VLDO.2, 33VLDO.3, C2.1, C3.1, D2.C, LS1.P, MCU.VSYS, PWR_BYP.1, R1.1
BTN1: MCU.GP0, R5.1, S1.2, S1.4
BTN2: MCU.GP1, R4.1, S2.2, S2.4
BUZZER: MCU.GP7, R7.1
DHT22_DATA: DHT22.2, MCU.GP8, R2.1
DSP_BUSY: DISPLAY.8, MCU.GP13
DSP_CLK: DISPLAY.4, MCU.GP10
DSP_CS: DISPLAY.5, MCU.GP9
DSP_DC: DISPLAY.6, MCU.GP14
DSP_DIN: DISPLAY.3, MCU.GP11
DSP_RST: DISPLAY.7, MCU.GP12
GND: 5VLDO.1, 33VLDO.1, C1.2, C2.2, C3.2, C4.2, CR1.1, CR2.1, DBG.2, DHT22.4, DISPLAY.2, H1.P1, H2.P1, H3.P1, H4.P1, IMU.2, MCU.AGND, MCU.GND@1, MCU.GND@2, MCU.GND@3, MCU.GND@4, MCU.GND@5, MCU.GND@6, MCU.GND@7, MCU.GND@8, PWR.N, PWR_BYP.2, Q1.2, R4.2, R5.2, R8.1, RST.2, SD.6, SD.10, SD.G1, SD.G2, SD.G3, SD.G4
IMU_INT: IMU.5, MCU.GP22
IMU_SCL: IMU.4, MCU.GP27_A1
IMU_SDA: IMU.3, MCU.GP26_A0
unnamed: CR2.2, R6.2
unnamed: CR1.2, R1.2
unnamed: D2.A, LS1.N, Q1.3
unnamed: Q1.1, R7.2, R8.2
unnamed: D1.C, R3.2
RUN: MCU.RUN, RST.1
SD_CD: MCU.GP20, R9.1, SD.9
SD_CLK: MCU.GP18, SD.5
SD_CS: MCU.GP17, R3.1, SD.2
SD_DI: MCU.GP19, SD.3
SD_DO: MCU.GP16, SD.7
STAT_LED: MCU.GP28_A2, R6.1
SWCLK: DBG.1, MCU.SWCLK
SWDIO: DBG.3, MCU.SWDIO
VCC: 5VLDO.3, C1.1, PWR.P
VDD: MCU.3V3, S1.1, S1.3, S2.1, S2.3

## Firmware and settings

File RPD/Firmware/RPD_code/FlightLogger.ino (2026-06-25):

#include "Waveshare_10Dof-D.h"
#include <Wire.h>
#include <SPI.h>
#include <SD.h>
#include "DHT.h"
#include "epd2in9_V2.h"
#include "epdpaint.h"

extern "C" {
  typedef struct {   
    uint16_t T1; int16_t T2; int16_t T3;
    uint16_t P1; int16_t P2; int16_t P3;
    int16_t P4; int16_t P5; int16_t P6;
    int16_t P7; int16_t P8; int16_t P9;
    int32_t T_fine;
  } BMP280_HandleTypeDef;
  
  extern BMP280_HandleTypeDef bmp280;
  uint8_t I2C_ReadOneByte(uint8_t DevAddr, uint8_t RegAddr);
  void I2C_WriteOneByte(uint8_t DevAddr, uint8_t RegAddr, uint8_t value);
}

// --- Configuration ---
const float LAUNCH_G = 3.0;
const unsigned long LAUNCH_DEBOUNCE_MS = 150;
const unsigned long APOGEE_CONFIRM_MS = 500;          // altitude decreasing this long = apogee passed
const float MIN_LAND_ALT_FT = 330.0;                  // landing only checked below this AGL
const float ALT_STABLE_BAND_FT = 10.0;                // altitude considered flat if change < this over the window
const unsigned long LANDED_CONFIRM_S = 5;
const unsigned long TIME_FAILSAFE_S = 180;            // last-resort backstop; ~2x real flight time
const float ACCEL_1G_RAW = 2048.0;                    // In 16g scale, 1g of force = 2048 raw value.

// --- Pins ---
const int BTN_0 = 0;
const int BTN_1 = 1;
const int LED_PIN = 28;
const int BUZZER_PIN = 7;
const int SD_DETECT_PIN = 20;

// DHT22 Sensor
#define DHTPIN 8
#define DHTTYPE DHT22
DHT dht(DHTPIN, DHTTYPE);

// e-Paper Display
unsigned char image[(EPD_WIDTH * EPD_HEIGHT) / 8];
Paint paint(image, EPD_WIDTH, EPD_HEIGHT);
Epd epd;

// SD Card (SPI0)
const int SD_CS = 17;

// State Machine
enum FlightState {
  STATE_IDLE,
  STATE_ARMED,
  STATE_ASCENT,
  STATE_DESCENT,
  STATE_LANDED
};

FlightState currentState = STATE_IDLE;
unsigned long launchTime = 0;
File dataFile;

bool lastBtn0State = LOW;
bool lastBtn1State = LOW;

// Telemetry Variables
float currentAltitude = 0.0;
float smoothedAltitude = 0.0;
float maxAltitude = -99999.0;
float groundAltitudeOffset = 0.0;
float currentTemp = 0.0;
float currentHumidity = 0.0;
float imuTemp = 0.0;
bool sdCardPresent = false;
bool displayNeedsUpdate = false;
float displayAltitudeOffset = 0.0;
unsigned long stateConditionStartTime = 0;
float windowMinAlt = 99999.0;
float windowMaxAlt = -99999.0;

// (Removed base altitude variables)

void setup() {
  Serial.begin(115200);
  delay(2000);
  Serial.println("--- Flight Logger ---");

  // 1. Setup Buttons, LED & Buzzer
  pinMode(BTN_0, INPUT);
  pinMode(BTN_1, INPUT);
  pinMode(SD_DETECT_PIN, INPUT_PULLUP);
  pinMode(LED_PIN, OUTPUT);
  digitalWrite(LED_PIN, LOW);
  pinMode(BUZZER_PIN, OUTPUT);
  
  // Beep when plugged in
  tone(BUZZER_PIN, 2000, 500); 

  // Initialize DHT22
  dht.begin();

  // 2. Setup IMU (I2C1 mapped to pins 26 and 27)
  Wire1.setSDA(26);
  Wire1.setSCL(27);
  IMU_EN_SENSOR_TYPE enMotionSensorType, enPressureType;
  imuInit(&enMotionSensorType, &enPressureType);
  if (enMotionSensorType != IMU_EN_SENSOR_TYPE_ICM20948) {
    Serial.println("IMU Motion sensor not found!");
  } else {
    Serial.println("IMU Initialized. Configuring to 16G full scale...");
    
    // Switch to User Bank 2
    I2C_WriteOneByte(0x68, 0x7F, 0x20);
    // Write REG_ADD_ACCEL_CONFIG (0x14)
    // 0x30 (DLPCFG_6) | 0x06 (FS_16g) | 0x01 (DLPF) = 0x37
    I2C_WriteOneByte(0x68, 0x14, 0x37);
    // Switch back to User Bank 0
    I2C_WriteOneByte(0x68, 0x7F, 0x00);

    Serial.println("Sensor warm-up complete.");
    // Warm up the filters by reading 50 times
    for (int i = 0; i < 50; i++) {
      int32_t pt, pp, pa;
      pressSensorDataGet(&pt, &pp, &pa);
      delay(20); 
    }
    Serial.println("Sensor warm-up complete.");
  }

  // 3. Setup SD Card (SPI0)
  if (digitalRead(SD_DETECT_PIN) == HIGH) {
    Serial.println("SD Card not inserted!");
    sdCardPresent = false;
    // Beep 3 times
    for (int i=0; i<3; i++) {
      tone(BUZZER_PIN, 1000, 200);
      delay(300);
    }
  } else {
    if (!SD.begin(SD_CS)) {
      Serial.println("SD Card initialization failed!");
      sdCardPresent = false;
      // Beep 3 times
      for (int i=0; i<3; i++) {
        tone(BUZZER_PIN, 1000, 200);
        delay(300);
      }
    } else {
      Serial.println("SD Card initialized.");
      sdCardPresent = true;
      
      // Write the STARTUP base values to the SD card immediately
      dataFile = SD.open("flightlog.csv", FILE_WRITE);
      if (dataFile) {
        dataFile.println("TimeMs,AccelX,AccelY,AccelZ,GyroX,GyroY,GyroZ,DHTTempC,DHTHum,IMUTempC,AltitudeM,Event");
        
        // Grab a quick initial reading
        IMU_ST_ANGLES_DATA stAngles;
        IMU_ST_SENSOR_DATA stGyroRawData;
        IMU_ST_SENSOR_DATA stAccelRawData;
        IMU_ST_SENSOR_DATA stMagnRawData;
        imuDataGet(&stAngles, &stGyroRawData, &stAccelRawData, &stMagnRawData);
        
        // Use our freshly implemented Bosch math for initial altitude
        float initialPressurePa = 101325.0;
        uint8_t xlsb = I2C_ReadOneByte(BMP280_ADDR, 0xF9);
        uint8_t lsb = I2C_ReadOneByte(BMP280_ADDR, 0xF8);
        uint8_t msb = I2C_ReadOneByte(BMP280_ADDR, 0xF7);
        int32_t adc_P = (msb << 12) | (lsb << 4) | (xlsb >> 4);
        int64_t var1, var2, p;
        var1 = ((int64_t)bmp280.T_fine) - 128000;
        var2 = var1 * var1 * (int64_t)bmp280.P6;
        var2 = var2 + ((var1*(int64_t)bmp280.P5)<<17);
        var2 = var2 + (((int64_t)bmp280.P4)<<35);
        var1 = ((var1 * var1 * (int64_t)bmp280.P3)>>8) + ((var1 * (int64_t)bmp280.P2)<<12);
        var1 = (((((int64_t)1)<<47)+var1))*((int64_t)bmp280.P1)>>33;
        if (var1 != 0) {
          p = 1048576 - adc_P;
          p = (((p<<31) - var2)*3125) / var1;
          var1 = (((int64_t)bmp280.P9) * (p>>13) * (p>>13)) >> 25;
          var2 = (((int64_t)bmp280.P8) * p) >> 19;
          p = ((p + var1 + var2) >> 8) + (((int64_t)bmp280.P7)<<4);
          initialPressurePa = (float)p / 256.0;
        }
        currentAltitude = 44330.0 * (1.0 - pow(initialPressurePa / 101325.0, 0.1903));
        smoothedAltitude = currentAltitude;
        
        dataFile.print(millis()); dataFile.print(",");
        dataFile.print(stAccelRawData.s16X); dataFile.print(",");
        dataFile.print(stAccelRawData.s16Y); dataFile.print(",");
        dataFile.print(stAccelRawData.s16Z); dataFile.print(",");
        dataFile.print(stGyroRawData.s16X); dataFile.print(",");
        dataFile.print(stGyroRawData.s16Y); dataFile.print(",");
        dataFile.print(stGyroRawData.s16Z); dataFile.print(",");
        dataFile.print(currentTemp); dataFile.print(",");
        dataFile.print(currentHumidity); dataFile.print(",");
        dataFile.print(0.0); dataFile.print(","); // Imutemp initially 0
        dataFile.print(currentAltitude); dataFile.println(",STARTUP");
        dataFile.close();
      }
    }
  }

  // 4. Setup e-Paper (SPI1)
  if (epd.Init() != 0) {
      Serial.println("e-Paper init failed!");
  } else {
      Serial.println("e-Paper initialized.");
      epd.ClearFrameMemory(0xFF);
      epd.DisplayFrame();
      paint.SetRotate(ROTATE_90); // Landscape
      displayNeedsUpdate = true; // Trigger first frame draw!
  }

  Serial.println("Ready! System is IDLE.");
}

void loop() {
  // Read Buttons
  bool currentBtn0State = digitalRead(BTN_0);
  bool currentBtn1State = digitalRead(BTN_1);

  // Read IMU
  IMU_ST_ANGLES_DATA stAngles;
  IMU_ST_SENSOR_DATA stGyroRawData;
  IMU_ST_SENSOR_DATA stAccelRawData;
  IMU_ST_SENSOR_DATA stMagnRawData;
  imuDataGet(&stAngles, &stGyroRawData, &stAccelRawData, &stMagnRawData);

  // Read BMP280 at 10Hz to prevent I2C collisions that cause garbled readings
  static unsigned long lastPressTime = 0;
  if (millis() - lastPressTime >= 100) {
    lastPressTime = millis();
    int32_t pressTemp, pressPressure, pressAltitude;
    pressSensorDataGet(&pressTemp, &pressPressure, &pressAltitude);

    imuTemp = pressTemp / 100.0; // BMP280 temperature is typically returned in 0.01 degrees C

    // BUGFIX: We bypass the Waveshare library's broken pressure math entirely
    // and implement the official Bosch 64-bit compensation formula using the raw I2C data.
    uint8_t xlsb = I2C_ReadOneByte(BMP280_ADDR, 0xF9);
    uint8_t lsb = I2C_ReadOneByte(BMP280_ADDR, 0xF8);
    uint8_t msb = I2C_ReadOneByte(BMP280_ADDR, 0xF7);
    int32_t adc_P = (msb << 12) | (lsb << 4) | (xlsb >> 4);

    int64_t var1, var2, p;
    var1 = ((int64_t)bmp280.T_fine) - 128000;
    var2 = var1 * var1 * (int64_t)bmp280.P6;
    var2 = var2 + ((var1*(int64_t)bmp280.P5)<<17);
    var2 = var2 + (((int64_t)bmp280.P4)<<35);
    var1 = ((var1 * var1 * (int64_t)bmp280.P3)>>8) + ((var1 * (int64_t)bmp280.P2)<<12);
    var1 = (((((int64_t)1)<<47)+var1))*((int64_t)bmp280.P1)>>33;

    float actualPressurePa = 101325.0; // Fallback
    if (var1 != 0) {
      p = 1048576 - adc_P;
      p = (((p<<31) - var2)*3125) / var1;
      var1 = (((int64_t)bmp280.P9) * (p>>13) * (p>>13)) >> 25;
      var2 = (((int64_t)bmp280.P8) * p) >> 19;
      p = ((p + var1 + var2) >> 8) + (((int64_t)bmp280.P7)<<4);
      actualPressurePa = (float)p / 256.0;
    }

    float newAltitude = 44330.0 * (1.0 - pow(actualPressurePa / 101325.0, 0.1903));
    
    // Outlier rejection: Ignore wildly impossible altitude readings
    if (newAltitude > -10000.0 && newAltitude < 100000.0) {
      currentAltitude = newAltitude;
      if (smoothedAltitude == 0.0) {
        smoothedAltitude = currentAltitude;
      } else {
        smoothedAltitude = smoothedAltitude * 0.8 + currentAltitude * 0.2;
      }
    }
  }

  // Calculate Accel Magnitude in Gs
  float accelMagG = sqrt(pow((float)stAccelRawData.s16X, 2) + pow((float)stAccelRawData.s16Y, 2) + pow((float)stAccelRawData.s16Z, 2)) / ACCEL_1G_RAW;
  float currentAglFt = (smoothedAltitude - groundAltitudeOffset) * 3.28084;
  
  if (currentState == STATE_ARMED || currentState == STATE_ASCENT || currentState == STATE_DESCENT) {
    // Continuous logging
    if (dataFile) {
      dataFile.print(millis()); dataFile.print(",");
      dataFile.print(stAccelRawData.s16X); dataFile.print(",");
      dataFile.print(stAccelRawData.s16Y); dataFile.print(",");
      dataFile.print(stAccelRawData.s16Z); dataFile.print(",");
      dataFile.print(stGyroRawData.s16X); dataFile.print(",");
      dataFile.print(stGyroRawData.s16Y); dataFile.print(",");
      dataFile.print(stGyroRawData.s16Z); dataFile.print(",");
      dataFile.print(currentTemp); dataFile.print(",");
      dataFile.print(currentHumidity); dataFile.print(",");
      dataFile.print(imuTemp); dataFile.print(",");
      dataFile.print(smoothedAltitude); dataFile.println(",LOG");
      
      static unsigned long lastFlush = 0;
      if (millis() - lastFlush > 1000) {
        dataFile.flush();
        lastFlush = millis();
      }
    }
  }

  // Failsafe check
  if ((currentState == STATE_ASCENT || currentState == STATE_DESCENT) && (millis() - launchTime > TIME_FAILSAFE_S * 1000)) {
    Serial.println("FAILSAFE: Time exceeded. Forcing LANDED state.");
    currentState = STATE_LANDED;
    if (dataFile) {
      dataFile.flush();
      dataFile.close();
    }
    digitalWrite(LED_PIN, LOW);
    tone(BUZZER_PIN, 2000, 1000);
    displayNeedsUpdate = true;
  }

  // State Machine Logic
  switch (currentState) {
    case STATE_IDLE:
      // Press Button 0 to ARM
      if (currentBtn0State == HIGH && lastBtn0State == LOW) {
        currentState = STATE_ARMED;
        Serial.println("System ARMED. Setting baseline and logging.");
        tone(BUZZER_PIN, 3000, 200); 
        
        groundAltitudeOffset = smoothedAltitude; 
        maxAltitude = 0.0;
        stateConditionStartTime = millis();

        dataFile = SD.open("flightlog.csv", FILE_WRITE);
        if (dataFile) {
          dataFile.println("TimeMs,AccelX,AccelY,AccelZ,GyroX,GyroY,GyroZ,DHTTempC,DHTHum,IMUTempC,AltitudeM,Event");
        }
        displayNeedsUpdate = true;
      }
      break;

    case STATE_ARMED:
      // Launch Detection
      if (accelMagG > LAUNCH_G) {
        if (millis() - stateConditionStartTime >= LAUNCH_DEBOUNCE_MS) {
          currentState = STATE_ASCENT;
          launchTime = millis();
          Serial.println("Launch detected! ASCENT.");
          tone(BUZZER_PIN, 4000, 1000); 
          digitalWrite(LED_PIN, HIGH);
          stateConditionStartTime = millis();
        }
      } else {
        stateConditionStartTime = millis(); // Reset debounce
      }
      break;

    case STATE_ASCENT:
      // Track Max AGL
      if (currentAglFt > maxAltitude) {
        maxAltitude = currentAglFt;
        stateConditionStartTime = millis(); // Reset apogee timer
      } else {
        // Apogee detection
        if (millis() - stateConditionStartTime >= APOGEE_CONFIRM_MS) {
          currentState = STATE_DESCENT;
          Serial.println("Apogee detected! DESCENT.");
          
          windowMinAlt = currentAglFt;
          windowMaxAlt = currentAglFt;
          stateConditionStartTime = millis(); 
        }
      }
      break;

    case STATE_DESCENT:
      // Landing Detection
      if (currentAglFt < windowMinAlt) windowMinAlt = currentAglFt;
      if (currentAglFt > windowMaxAlt) windowMaxAlt = currentAglFt;

      if (currentAglFt < MIN_LAND_ALT_FT && ((windowMaxAlt - windowMinAlt) < ALT_STABLE_BAND_FT) && (accelMagG > 0.8 && accelMagG < 1.2)) {
        if (millis() - stateConditionStartTime >= LANDED_CONFIRM_S * 1000) {
          currentState = STATE_LANDED;
          Serial.println("Landing detected! LANDED.");
          if (dataFile) {
            dataFile.flush();
            dataFile.close();
          }
          digitalWrite(LED_PIN, LOW);
          tone(BUZZER_PIN, 2000, 1000); 
          displayNeedsUpdate = true;
        }
      } else {
        // Reset landing window timer and bounds if conditions fail
        stateConditionStartTime = millis();
        windowMinAlt = currentAglFt;
        windowMaxAlt = currentAglFt;
      }
      break;

    case STATE_LANDED:
      // System is stopped. Max altitude is preserved.
      // Press Button 0 to reset back to IDLE
      if (currentBtn0State == HIGH && lastBtn0State == LOW) {
        currentState = STATE_IDLE;
        maxAltitude = -99999.0;
        Serial.println("System Reset to IDLE.");
        tone(BUZZER_PIN, 1000, 200);
        displayNeedsUpdate = true;
      }
      break;
  }

  // Relative Altitude Reset Logic (Button 1)
  if (currentBtn1State == HIGH && lastBtn1State == LOW) {
    displayAltitudeOffset = smoothedAltitude;
    Serial.println("Display altitude zeroed to relative!");
    tone(BUZZER_PIN, 2500, 100);
    displayNeedsUpdate = true;
  }

  lastBtn0State = currentBtn0State;
  lastBtn1State = currentBtn1State;

  // Read DHT22 slowly (Max 1 reading every 2 seconds)
  // To avoid blocking the fast recording loop too much, we could skip this during RECORDING,
  // but requirements say "must also write all... and dht22".
  static unsigned long lastDhtTime = 0;
  if (millis() - lastDhtTime >= 2000) {
    lastDhtTime = millis();
    float t = dht.readTemperature();
    float h = dht.readHumidity();
    if (!isnan(t)) currentTemp = t;
    if (!isnan(h)) currentHumidity = h;
  }

  // Update e-Paper Display on demand
  if (displayNeedsUpdate) {
    displayNeedsUpdate = false;
    
    paint.Clear(1); // UNCOLORED (white)
    char buf[32];
    paint.DrawStringAt(10, 10, "Flight Logger", &Font16, 0); // COLORED (black)
    
    const char* stateStr = "IDLE";
    if (currentState == STATE_ARMED) stateStr = "ARMED";
    else if (currentState == STATE_ASCENT) stateStr = "ASCENT";
    else if (currentState == STATE_DESCENT) stateStr = "DESCENT";
    else if (currentState == STATE_LANDED) stateStr = "LANDED";
    
    snprintf(buf, sizeof(buf), "State: %s", stateStr);
    paint.DrawStringAt(10, 35, buf, &Font16, 0);
    
    if (currentState == STATE_IDLE) {
      float relativeAltFt = (smoothedAltitude - displayAltitudeOffset) * 3.28084;
      snprintf(buf, sizeof(buf), "Alt: %.1f ft", relativeAltFt);
      paint.DrawStringAt(10, 55, buf, &Font16, 0);
      snprintf(buf, sizeof(buf), "Max AGL: -- ft");
      paint.DrawStringAt(10, 75, buf, &Font16, 0);
    } else {
      float currentAglFt = (smoothedAltitude - groundAltitudeOffset) * 3.28084;
      snprintf(buf, sizeof(buf), "AGL: %.1f ft", currentAglFt);
      paint.DrawStringAt(10, 55, buf, &Font16, 0);
      snprintf(buf, sizeof(buf), "Max AGL: %.1fft", maxAltitude);
      paint.DrawStringAt(10, 75, buf, &Font16, 0);
    }
    
    if (!sdCardPresent) {
      paint.DrawStringAt(10, 95, "NO SD CARD!", &Font16, 0);
    } else {
      snprintf(buf, sizeof(buf), "Temp: %.1fC", currentTemp);
      paint.DrawStringAt(10, 95, buf, &Font16, 0);
    }
    
    epd.SetFrameMemory(paint.GetImage(), 0, 0, EPD_WIDTH, EPD_HEIGHT);
    epd.DisplayFrame();
  }
  
  // Optional: small delay to not overwhelm I2C if not recording
  if (currentState != STATE_RECORDING) {
    delay(10);
  }
}

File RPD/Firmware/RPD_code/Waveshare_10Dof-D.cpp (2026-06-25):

/**
  ******************************************************************************
  * @file    Waveshare_10Dof-D.cpp
  * @author  Waveshare Team
  * @version V1.0
  * @date    Dec-2018
  * @brief   T
  
  ******************************************************************************
  * @attention
  *
  * THE PRESENT FIRMWARE WHICH IS FOR GUIDANCE ONLY AIMS AT PROVIDING CUSTOMERS
  * WITH CODING INFORMATION REGARDING THEIR PRODUCTS IN ORDER FOR THEM TO SAVE
  * TIME. AS A RESULT, WAVESHARE SHALL NOT BE HELD LIABLE FOR ANY
  * DIRECT, INDIRECT OR CONSEQUENTIAL DAMAGES WITH RESPECT TO ANY CLAIMS ARISING
  * FROM THE CONTENT OF SUCH FIRMWARE AND/OR THE USE MADE BY CUSTOMERS OF THE
  * CODING INFORMATION CONTAINED HEREIN IN CONNECTION WITH THEIR PRODUCTS.
  *
  * <h2><center>&copy; COPYRIGHT 2018 Waveshare</center></h2>
  ******************************************************************************
  */
#include "Waveshare_10Dof-D.h"
#include <Wire.h>
  
IMU_ST_SENSOR_DATA gstGyroOffset ={0,0,0};  
#ifdef __cplusplus
extern "C" {
#endif

void imuAHRSupdate(float gx, float gy, float gz, float ax, float ay, float az, float mx, float my, float mz);
float invSqrt(float x);

void icm20948init(void);
bool icm20948Check(void);
void icm20948GyroRead(int16_t* ps16X, int16_t* ps16Y, int16_t* ps16Z);
void icm20948AccelRead(int16_t* ps16X, int16_t* ps16Y, int16_t* ps16Z);
void icm20948MagRead(int16_t* ps16X, int16_t* ps16Y, int16_t* ps16Z);
bool icm20948MagCheck(void);
void icm20948CalAvgValue(uint8_t *pIndex, int16_t *pAvgBuffer, int16_t InVal, int32_t *pOutVal);
void icm20948GyroOffset(void);
void icm20948ReadSecondary(uint8_t u8I2CAddr, uint8_t u8RegAddr, uint8_t u8Len, uint8_t *pu8data);
void icm20948WriteSecondary(uint8_t u8I2CAddr, uint8_t u8RegAddr, uint8_t u8data);
bool icm20948Check(void);

bool bmp280Check(void);
void bmp280Init(void);
/******************************************************************************
 * interface driver                                                           *
 ******************************************************************************/
uint8_t I2C_ReadOneByte(uint8_t DevAddr, uint8_t RegAddr)
{
  uint8_t value;

  Wire1.beginTransmission(DevAddr);
  Wire1.write((byte)RegAddr);
  Wire1.endTransmission();

  Wire1.requestFrom(DevAddr, (byte)1);
  value = Wire1.read();

  return value;
}

void I2C_WriteOneByte(uint8_t DevAddr, uint8_t RegAddr, uint8_t value)
{
  Wire1.beginTransmission(DevAddr);
  Wire1.write(RegAddr);
  Wire1.write(value);
  Wire1.endTransmission();
}
/******************************************************************************
 * IMU module                                                                 *
 ******************************************************************************/
#define Kp 4.50f   // proportional gain governs rate of convergence to accelerometer/magnetometer
#define Ki 1.0f    // integral gain governs rate of convergence of gyroscope biases

float angles[3];
float q0, q1, q2, q3; 

void imuInit(IMU_EN_SENSOR_TYPE *penMotionSensorType, IMU_EN_SENSOR_TYPE *penPressureType)
{
  bool bRet = false;
  Wire1.begin();
  bRet = icm20948Check();
  if( true == bRet)
  {
    *penMotionSensorType = IMU_EN_SENSOR_TYPE_ICM20948;
    icm20948init();
  }
  else
  {
    *penMotionSensorType = IMU_EN_SENSOR_TYPE_NULL;
  }
  
  bRet = bmp280Check();
  if( true == bRet)
  {
    *penPressureType = IMU_EN_SENSOR_TYPE_BMP280;
    bmp280Init();
  }
  else
  {
    *penPressureType = IMU_EN_SENSOR_TYPE_NULL;
  }

  q0 = 1.0f;  
  q1 = 0.0f;
  q2 = 0.0f;
  q3 = 0.0f;

  return;
}

void imuDataGet(IMU_ST_ANGLES_DATA *pstAngles, 
                IMU_ST_SENSOR_DATA *pstGyroRawData,
                IMU_ST_SENSOR_DATA *pstAccelRawData,
                IMU_ST_SENSOR_DATA *pstMagnRawData)
{
  float MotionVal[9];
  int16_t s16Gyro[3], s16Accel[3], s16Magn[3];

  icm20948AccelRead(&s16Accel[0], &s16Accel[1], &s16Accel[2]);
  icm20948GyroRead(&s16Gyro[0], &s16Gyro[1], &s16Gyro[2]);
  icm20948MagRead(&s16Magn[0], &s16Magn[1], &s16Magn[2]);

  MotionVal[0]=s16Gyro[0]/32.8;
  MotionVal[1]=s16Gyro[1]/32.8;
  MotionVal[2]=s16Gyro[2]/32.8;
  MotionVal[3]=s16Accel[0];
  MotionVal[4]=s16Accel[1];
  MotionVal[5]=s16Accel[2];
  MotionVal[6]=s16Magn[0];
  MotionVal[7]=s16Magn[1];
  MotionVal[8]=s16Magn[2];
  imuAHRSupdate((float)MotionVal[0] * 0.0175, (float)MotionVal[1] * 0.0175, (float)MotionVal[2] * 0.0175,
                (float)MotionVal[3], (float)MotionVal[4], (float)MotionVal[5], 
                (float)MotionVal[6], (float)MotionVal[7], MotionVal[8]);


  pstAngles->fPitch = asin(-2 * q1 * q3 + 2 * q0* q2)* 57.3; // pitch
  pstAngles->fRoll = atan2(2 * q2 * q3 + 2 * q0 * q1, -2 * q1 * q1 - 2 * q2* q2 + 1)* 57.3; // roll
  pstAngles->fYaw = atan2(-2 * q1 * q2 - 2 * q0 * q3, 2 * q2 * q2 + 2 * q3 * q3 - 1) * 57.3; 

  pstGyroRawData->s16X = s16Gyro[0];
  pstGyroRawData->s16Y = s16Gyro[1];
  pstGyroRawData->s16Z = s16Gyro[2];

  pstAccelRawData->s16X = s16Accel[0];
  pstAccelRawData->s16Y = s16Accel[1];
  pstAccelRawData->s16Z  = s16Accel[2];

  pstMagnRawData->s16X = s16Magn[0];
  pstMagnRawData->s16Y = s16Magn[1];
  pstMagnRawData->s16Z = s16Magn[2];  

  return;  
}
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

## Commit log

2026-04-30 Added folders for each division into repo
    [Customer Payload Dummy.stl, LVA_XT30_V1.ipt, LVA_XT30_V1.stl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]
2026-05-06 Create Requirement Specifications.csv
    [Requirement Specifications.csv]
2026-05-06 Added Requirement Specifications to repo
    [Requirement Specifications.csv]
2026-05-06 Update Requirement Specifications.csv
    [Requirement Specifications.csv]
2026-05-06 Latest Rocket Design
    Current design on OpenRocket
2026-05-12 changed nosecone f3d file
    [NOSECONE 2 v2.f3d, nose cone v2.f3d]
2026-06-04 Add Arduino code for successful squat movement
2026-06-25 renamed rocket mount file names and moved them to structures folder
    [Final_rocket_mount_1.f3d, Final_rocket_mount_2.f3d]
2026-06-25 Moved structures cad file out of openrocket folder and final open rocket file into open rocket folder
    [NOSECONE 2 v2.f3d, NOSECONE V3 v2.f3d, NOSECONE V3.f3d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]
2026-06-25 reanamed payloads folder to CPD and rideshare payloadds folder to RPD
    [Customer Payload Dummy.stl, LVA_XT30_V1.ipt, LVA_XT30_V1.stl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]
2026-06-25 Deleted test code folder and added full sections to rpd
    The rpd folder now contains a hardware and firmware folder containing cad, pcb and code. in addition a readme has been added and the python file for reading the rpd output
    [alt_rpd_pcb.brd, alt_rpd_schematic.sch, flightlog.csv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]
2026-06-25 renamed fins files and moved them to structures folder
    [Final_fins.dxf, Fins please.dxf, final fin.dxf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]
2026-06-25 moved nosecone f3d files from structures to recovery folder
    [NOSECONE 2 v2.f3d, NOSECONE V3 v2.f3d, NOSECONE V3.f3d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]
2026-06-25 reorganised cpd folder and added vehicle launch adapter step file
    [Customer Payload Dummy.stl, LVA_XT30_V1.ipt, LVA_XT30_V1.stl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]
2026-06-25 added rpd casing to rpd folder
    [rpd_casing_front.step, rpd_casing_rear.step]
2026-06-25 changed names of final chamber in recovery folder and added v1 versions
    [Final_flashpaper_chamber_inner.f3d, Final_flashpaper_chamber_outer.f3d, flashpaper_chamber_inner_v1.step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]
2026-06-25 added final top motor casing to structures folder
    [Final_motor_casing_mount_top.step]
2026-06-25 created avionics folder in repo and added battery holder step file
    [avionics_battery_holder.step]
2026-06-25 created systems folder and moved requirement specifications to it
    [Requirement Specifications.csv]
2026-06-25 Created propulsion folder and moved all motor related files to it
    [Final_motor_casing_mount_top.step, Final_rocket_mount_1.f3d, Final_rocket_mount_2.f3d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]
2026-06-25 renamed f3d files in propulsion for uniformity
    [rocket_mount_top_v1.f3d, roket_mount_bottom_v1.f3d, roket_mount_top_v2.f3d]
2026-06-26 added rpd board schematic and layout images to rpd hardware folder
2026-06-26 Fix typos and add figures in README
    Corrected typographical errors in board revision descriptions and added figures for clarity.
2026-06-26 rearanged rpd hardware folder
    added layout gerber and source folders and moved original files into their respective folders
    [alt_rpd_pcb.brd, alt_rpd_schematic.sch, rpd_casing_front.step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]
2026-06-26 Fix typos in board revision descriptions
2026-06-26 Add schematic image to README
    Updated README with schematic image reference.
2026-06-26 added v2 schematic pdf to rpd layout directory
2026-06-26 moved schematic pdf out of layout section and into general hardware directory and added BOM files
    [BOM_RPD.csv, BOM_RPD.xlsx]
2026-06-26 Fix schematic PDF link in README
    Updated the path to the schematic PDF in the README.
2026-06-27 Update requirement specifications CSV
    [Requirement Specifications.csv]
2026-06-27 Revamped requirement specifications csv
    Updated requirement specifications with revisions and additional details for various components.
    [Requirement Specifications.csv]

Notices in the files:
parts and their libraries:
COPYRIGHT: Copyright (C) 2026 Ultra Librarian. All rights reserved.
